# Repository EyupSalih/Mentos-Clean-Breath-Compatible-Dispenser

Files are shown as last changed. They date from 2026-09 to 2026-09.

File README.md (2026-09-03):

# Mentos Clean Breath Compatible V7 Dual‑Magazine Pocket Dispenser

> 3D-printable, spring-fed, dual-magazine pocket dispenser designed to fit **Mentos Clean Breath** tablets.  
> **30-tablet capacity (15 + 15)**, anti-jam cutoff shuttle, closed outer shell, removable magazines, single-button spring release, sliding bottom service cover and a hinged dust flap.

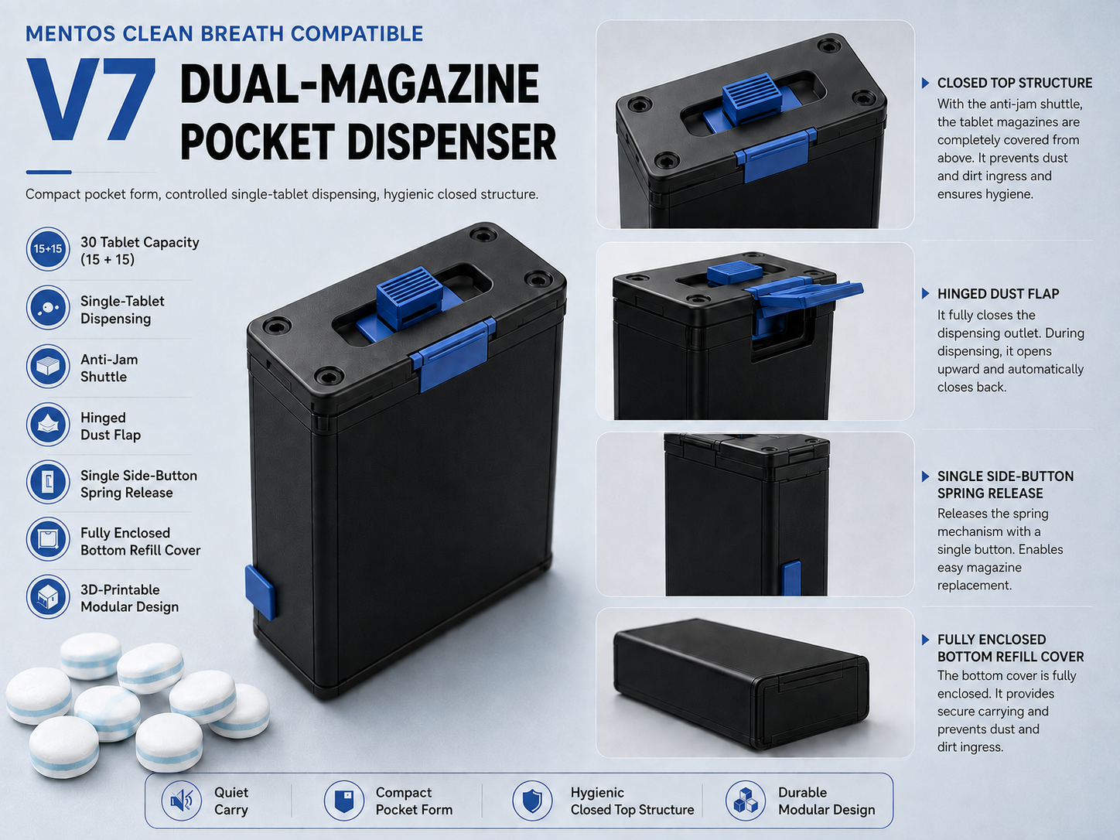
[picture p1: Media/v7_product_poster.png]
V7 product overview

Türkçe versiyon için "Media/v7_product_poster_TR.png"

## Project status

**V7 — functional CAD release**

The current digital CAD audit reports **no critical rigid-body collisions in the tested assembly and motion states**.  
This is **not** a physical certification. Before relying on the device for everyday use, validate the real print tolerances, spring force, TPU behavior, tablet batch variation and food-contact suitability of the materials you choose.

Nominal tablet model used in CAD:

- Diameter: **11.2 mm**
- Thickness: **5.9 mm**
- Maximum design envelope used in checks: **Ø11.55 × 6.20 mm**

## Key features

- **30-tablet capacity** — two removable 15-tablet magazines
- **Spring + follower feed system** in each magazine
- **Double-J follower lock** so the magazines can be filled while the springs remain restrained
- **Single side release button** releases both magazine followers after the case is closed
- **Closed exterior shell** — no long follower slots on the outside
- **Dual-pocket cutoff shuttle** — blocks the feed openings while moving to reduce double-feeds/jams
- **Raised thumb tab** for easier left/right operation
- **Hinged output dust flap**
- **Full-width sliding bottom service cover** — routine refill does not require removing the top screws
- **TPU/silicone anti-rattle elements**
- STEP source geometry, printable STL files, assembly-state CAD, hardware references and audit files included

## How it works

1. Remove a magazine from the body.
2. Remove the TPU feed ring.
3. Use the refill push-twist tool to push the follower down and rotate it into the **double-J lock**.
4. Load **15 tablets**.
5. Reinstall the TPU feed ring.
6. Repeat for the second magazine.
7. Insert both magazines into the chassis **while their springs are still locked**.
8. Close the sliding bottom cover.
9. Press the recessed side button once; the internal common release bar unlocks both followers.
10. Move the top shuttle left or right to bring one tablet to the center output.
11. Open the dust flap and remove the tablet.
12. Return the shuttle to the center/feed position.

## Assembly video

A detailed X-ray-style assembly, refill and usage video is included:

**[Watch / download the V7 assembly video](Media/V7_XRAY_assembly_fill_use_30fps.mp4)**

The video uses transparent/X-ray views where the outer shell would otherwise hide the internal mechanism.

## Repository structure

```text
.
├── README.md
├── README_TR.md
├── LICENSE.md
├── LICENSE-CAD.md
├── LICENSE-SOFTWARE
├── GITHUB_SETUP.md
├── ASSEMBLY_STATES/
│   ├── 01_COMPLETE_30_LOADED_RELEASED.step
│   ├── 02_CUTAWAY_INTERNALS.step
│   └── ...
├── STEP_parts/
│   ├── 01_lower_chassis_closed_shell.step
│   ├── 02_transfer_base_metering_deck.step
│   ├── 03_top_cap_real_screw_access.step
│   └── ...
├── STL_printable/
│   ├── 01_lower_chassis_closed_shell.stl
│   ├── 02_transfer_base_metering_deck.stl
│   ├── 03_top_cap_real_screw_access.stl
│   └── ...
├── REFERENCE_hardware/
├── AUDIT/
├── SOURCE/
└── media/
    ├── v7_product_poster.png
    └── V7_XRAY_assembly_fill_use_30fps.mp4
```

For the detailed Turkish mechanical description, see **[README_TR.md](README_TR.md)**.

## Main printable parts

| No. | Part | Suggested material | Qty |
|---:|---|---|---:|
| 01 | Lower chassis / closed shell | PETG / ASA | 1 |
| 02 | Transfer base / metering deck | PETG / ASA | 1 |
| 03 | Top cap | PETG / ASA | 1 |
| 04 | Left magazine | PETG / ASA | 1 |
| 05 | Right magazine | PETG / ASA | 1 |
| 06 | Double-stem follower | PETG / ASA | 2 |
| 07 | Feed ring | TPU | 2 |
| 08 | Dual-pocket cutoff shuttle | PETG / ASA | 1 |
| 09 | Common release bar | PETG / ASA | 1 |
| 10 | Side-button dust seal | TPU | 1 |
| 11 | Output dust flap | TPU | 1 |
| 12 | Sliding bottom outer cover | PETG / ASA | 1 |
| 13 | Bottom preload pad | TPU | 2 |
| 14 | Refill push-twist tool | PETG / ASA | 1 |

See `AUDIT/V7_BOM_TR.csv` for the full bill of materials and hardware references.

## Referenced hardware

The repository contains reference CAD for the hardware used by the design, including:

- 2 × main compression springs
- 1 × release-button return spring
- 4 × M2.5 countersunk screws
- 4 × M2.5 heat-set inserts
- M3 shuttle center detent ball plunger
- M3 bottom-cover detent ball plunger
- 1.5 mm food-grade silicone cord

**Reference CAD is dimensional guidance only.** Match the physical hardware you actually purchase and verify dimensions before printing the final parts.

## Printing and material notes

PETG or ASA is recommended for the main rigid parts. Flexible sealing/feed parts are designed around TPU-type behavior.

If this device will directly contact food/tablets:

- choose materials whose manufacturer documents suitability for your intended contact use,
- consider nozzle, printer and post-processing contamination,
- clean parts appropriately,
- do not assume that a material is food-safe solely because it is sold as PETG or TPU.

## CAD audit and limitations

Audit material is stored in `AUDIT/`.

The digital checks cover selected rigid-body collisions, assembly paths and motion states. They **cannot** fully predict:

- FDM dimensional error
- layer orientation strength
- wear after repeated cycling
- actual spring-force curve
- TPU Shore hardness differences
- tablet manufacturing variation
- long-term dust sealing
- real-world impact/drop behavior

Physical prototype testing remains necessary.

## Licensing

This repository uses **split licensing**:

- CAD, STEP/STL files, documentation, images and project media: **CC BY-NC-SA 4.0**
- Source code / utility scripts in `SOURCE/`: **MIT License**

See [LICENSE.md](LICENSE.md), [LICENSE-CAD.md](LICENSE-CAD.md) and [LICENSE-SOFTWARE](LICENSE-SOFTWARE).

The non-commercial restriction means the design files may not be used commercially under the CC license without separate permission from the rights holder.

## Trademark / affiliation disclaimer

**Mentos** and **Mentos Clean Breath** are trademarks of their respective owners.  
This is an **independent, unofficial compatibility project** and is not affiliated with, sponsored by, approved by or endorsed by Mentos or Perfetti Van Melle.

The product name is used only to identify the tablet format the design is intended to fit.

## Contributions and modifications

Issues, tolerance measurements, print results and mechanical improvements are welcome.

If you publish a modified version of the licensed CAD/design material, follow the attribution and ShareAlike requirements in `LICENSE-CAD.md`.

---

### Türkçe kısa özet

Bu repo, Mentos Clean Breath tabletleri için tasarlanmış **15 + 15 kapasiteli çift şarjörlü, yay beslemeli V7 cep dispenserinin** STEP/STL dosyalarını, montaj durumlarını, audit dosyalarını ve detaylı X-ray montaj videosunu içerir. Ayrıntılı Türkçe teknik açıklama için **[README_TR.md](README_TR.md)** dosyasına bakın.

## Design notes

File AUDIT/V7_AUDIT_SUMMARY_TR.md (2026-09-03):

# V7 CAD Audit Özeti — Magazine Retention V2

Şarjör tutucu kasa revizyonunda önceki alt C-kılavuzların, şarjör alttan takılırken kilitli/18° döndürülmüş follower saplarının montaj yoluna girdiği tespit edildi. Final oturma konumu çarpışmasızdı; sorun yalnızca montaj yolunda yaklaşık -8 mm ara konumda oluşuyordu.

Yeni kasada follower saplarının ön/arka süpürme bölgesi tamamen açık bırakıldı. Şarjörleri Y yönünde tutmak için mevcut yan raylara bağlı, follower saplarından uzakta kalan dört diyagonal sarma kılavuzu kullanıldı. Nominal şarjör ile kılavuz arasında yaklaşık 0,35 mm radyal çalışma boşluğu korunur.

Kontrol edilen kritik zincirler: tek bağlı basılabilir katılar, follower stroku, çift taraflı J kilidi, yay kilitliyken şarjörün alttan tüm montaj yolu, tek yan butonlu ortak release bar, sürgülü alt kapak, cutoff shuttle, ikinci tablet anti-jam düzlemi, worst-case tablet çıkışı, feed keepout ve vida/tornavida erişimi.

Son gate: **CAD_GATE_PASS / 0 kritik hata**.

Not: CAD audit fiziksel baskı doğrulamasının yerine geçmez; FDM toleransı, gerçek yay kuvveti, TPU sertliği ve gerçek şeker parti toleransları baskıda kontrol edilmelidir.

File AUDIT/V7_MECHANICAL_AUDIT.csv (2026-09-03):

test | value | expected | severity | note
connected_solids::chassis | 1 | 1 | CRITICAL
valid_shape::chassis | 1 | 1 | CRITICAL
connected_solids::transfer_base | 1 | 1 | CRITICAL
valid_shape::transfer_base | 1 | 1 | CRITICAL
connected_solids::top_cap | 1 | 1 | CRITICAL
valid_shape::top_cap | 1 | 1 | CRITICAL
connected_solids::magazine | 1 | 1 | CRITICAL
valid_shape::magazine | 1 | 1 | CRITICAL
connected_solids::follower | 1 | 1 | CRITICAL
valid_shape::follower | 1 | 1 | CRITICAL
connected_solids::shuttle | 1 | 1 | CRITICAL
valid_shape::shuttle | 1 | 1 | CRITICAL
connected_solids::release_bar | 1 | 1 | CRITICAL
valid_shape::release_bar | 1 | 1 | CRITICAL
connected_solids::bottom_cover | 1 | 1 | CRITICAL
valid_shape::bottom_cover | 1 | 1 | CRITICAL
magL_vs_chassis | 0.0 | 0 | CRITICAL
magR_vs_chassis | 0.0 | 0 | CRITICAL
base_vs_chassis | 0.0 | 0 | CRITICAL
topcap_vs_base | 0.0 | 0 | CRITICAL
bottomcover_vs_chassis_closed | 0.0 | 0 | CRITICAL
releasebar_rest_vs_chassis | 0.0 | 0 | CRITICAL
releasebar_rest_vs_magL | 0.0 | 0 | CRITICAL
releasebar_rest_vs_magR | 0.0 | 0 | CRITICAL
L_follower_vs_mag_z12.4 | 0.0 | 0 | CRITICAL
L_follower_vs_closed_shell_z12.4 | 0.0 | 0 | CRITICAL
L_follower_vs_mag_z20 | 0.0 | 0 | CRITICAL
L_follower_vs_closed_shell_z20 | 0.0 | 0 | CRITICAL
L_follower_vs_mag_z40 | 0.0 | 0 | CRITICAL
L_follower_vs_closed_shell_z40 | 0.0 | 0 | CRITICAL
L_follower_vs_mag_z65 | 0.0 | 0 | CRITICAL
L_follower_vs_closed_shell_z65 | 0.0 | 0 | CRITICAL
L_follower_vs_mag_z90 | 0.0 | 0 | CRITICAL
L_follower_vs_closed_shell_z90 | 0.0 | 0 | CRITICAL
L_follower_vs_mag_z103.7 | 0.0 | 0 | CRITICAL
L_follower_vs_closed_shell_z103.7 | 0.0 | 0 | CRITICAL
R_follower_vs_mag_z12.4 | 0.0 | 0 | CRITICAL
R_follower_vs_closed_shell_z12.4 | 0.0 | 0 | CRITICAL
R_follower_vs_mag_z20 | 0.0 | 0 | CRITICAL
R_follower_vs_closed_shell_z20 | 0.0 | 0 | CRITICAL
R_follower_vs_mag_z40 | 0.0 | 0 | CRITICAL
R_follower_vs_closed_shell_z40 | 0.0 | 0 | CRITICAL
R_follower_vs_mag_z65 | 0.0 | 0 | CRITICAL
R_follower_vs_closed_shell_z65 | 0.0 | 0 | CRITICAL
R_follower_vs_mag_z90 | 0.0 | 0 | CRITICAL
R_follower_vs_closed_shell_z90 | 0.0 | 0 | CRITICAL
R_follower_vs_mag_z103.7 | 0.0 | 0 | CRITICAL
R_follower_vs_closed_shell_z103.7 | 0.0 | 0 | CRITICAL
doubleJ_rotation_0 | 0.0 | 0 | CRITICAL | Both stems rotate within symmetric J windows.
doubleJ_rotation_6 | 0.0 | 0 | CRITICAL | Both stems rotate within symmetric J windows.
doubleJ_rotation_12 | 0.0 | 0 | CRITICAL | Both stems rotate within symmetric J windows.
doubleJ_rotation_18 | 0.000324 | 0 | CRITICAL | Both stems rotate within symmetric J windows.
L_locked_mag_insert_-60 | 0.0 | 0 | CRITICAL | Spring remains locked while inserting magazine.
L_locked_mag_insert_-35 | 0.0 | 0 | CRITICAL | Spring remains locked while inserting magazine.
L_locked_mag_insert_-18 | 0.0 | 0 | CRITICAL | Spring remains locked while inserting magazine.
L_locked_mag_insert_-8 | 0.0 | 0 | CRITICAL | Spring remains locked while inserting magazine.
L_locked_mag_insert_0 | 0.0 | 0 | CRITICAL | Spring remains locked while inserting magazine.
R_locked_mag_insert_-60 | 0.0 | 0 | CRITICAL | Spring remains locked while inserting magazine.
R_locked_mag_insert_-35 | 0.0 | 0 | CRITICAL | Spring remains locked while inserting magazine.
R_locked_mag_insert_-18 | 0.0 | 0 | CRITICAL | Spring remains locked while inserting magazine.
R_locked_mag_insert_-8 | 0.0 | 0 | CRITICAL | Spring remains locked while inserting magazine.
R_locked_mag_insert_0 | 0.0 | 0 | CRITICAL | Spring remains locked while inserting magazine.
release_sweep_0 | 0.0 | 0 | CRITICAL | Internal bar clears rigid housing.
release_sweep_0.5 | 0.0 | 0 | CRITICAL | Internal bar clears rigid housing.
release_sweep_1.0 | 0.0 | 0 | CRITICAL | Internal bar clears rigid housing.
release_sweep_1.5 | 0.0 | 0 | CRITICAL | Internal bar clears rigid housing.
release_sweep_2.0 | 0.0 | 0 | CRITICAL | Internal bar clears rigid housing.
release_sweep_2.45 | 0.0 | 0 | CRITICAL | Internal bar clears rigid housing.
L_release_contact_rest | 0.0 | 0 | CRITICAL
L_release_contact_press | 4.250313 | >0 intentional | CRITICAL | Pusher nose reaches locked rear stem.
R_release_contact_rest | 0.0 | 0 | CRITICAL
R_release_contact_press | 4.250313 | >0 intentional | CRITICAL | Pusher nose reaches locked rear stem.
bottom_cover_slide_y34 | 0.0 | 0 | CRITICAL | Full outer cover slides without screw removal.
bottom_cover_slide_y28 | 0.0 | 0 | CRITICAL | Full outer cover slides without screw removal.
bottom_cover_slide_y22 | 0.0 | 0 | CRITICAL | Full outer cover slides without screw removal.
bottom_cover_slide_y16 | 0.0 | 0 | CRITICAL | Full outer cover slides without screw removal.
bottom_cover_slide_y10 | 0.0 | 0 | CRITICAL | Full outer cover slides without screw removal.
bottom_cover_slide_y5 | 0.0 | 0 | CRITICAL | Full outer cover slides without screw removal.
bottom_cover_slide_y0 | 0.0 | 0 | CRITICAL | Full outer cover slides without screw removal.
shuttle_rigid_-9.5 | 0.0 | 0 | CRITICAL
L_carried_nom_-9.5 | 0.0 | 0 | CRITICAL
L_carried_MAX_-9.5 | 0.0 | 0 | CRITICAL
R_carried_nom_-9.5 | 0.0 | 0 | CRITICAL
R_carried_MAX_-9.5 | 0.0 | 0 | CRITICAL
L_next_vs_cutoff_-9.5 | 0.0 | 0 | CRITICAL | Second candy stays below moving cutoff plane.
R_next_vs_cutoff_-9.5 | 0.0 | 0 | CRITICAL | Second candy stays below moving cutoff plane.
shuttle_rigid_-6.33 | 0.0 | 0 | CRITICAL
L_carried_nom_-6.33 | 0.0 | 0 | CRITICAL
L_carried_MAX_-6.33 | 0.0 | 0 | CRITICAL
R_carried_nom_-6.33 | 0.0 | 0 | CRITICAL
R_carried_MAX_-6.33 | 0.0 | 0 | CRITICAL
L_next_vs_cutoff_-6.33 | 0.0 | 0 | CRITICAL | Second candy stays below moving cutoff plane.
R_next_vs_cutoff_-6.33 | 0.0 | 0 | CRITICAL | Second candy stays below moving cutoff plane.
shuttle_rigid_-3.17 | 0.0 | 0 | CRITICAL
L_carried_nom_-3.17 | 0.0 | 0 | CRITICAL
L_carried_MAX_-3.17 | 0.0 | 0 | CRITICAL
R_carried_nom_-3.17 | 0.0 | 0 | CRITICAL
R_carried_MAX_-3.17 | 0.0 | 0 | CRITICAL
L_next_vs_cutoff_-3.17 | 0.0 | 0 | CRITICAL | Second candy stays below moving cutoff plane.
R_next_vs_cutoff_-3.17 | 0.0 | 0 | CRITICAL | Second candy stays below moving cutoff plane.
shuttle_rigid_0 | 0.0 | 0 | CRITICAL
L_carried_nom_0 | 0.0 | 0 | CRITICAL
L_carried_MAX_0 | 0.0 | 0 | CRITICAL
R_carried_nom_0 | 0.0 | 0 | CRITICAL
R_carried_MAX_0 | 0.0 | 0 | CRITICAL
L_next_vs_cutoff_0 | 0.0 | 0 | CRITICAL | Second candy stays below moving cutoff plane.
R_next_vs_cutoff_0 | 0.0 | 0 | CRITICAL | Second candy stays below moving cutoff plane.
shuttle_rigid_3.17 | 0.0 | 0 | CRITICAL
L_carried_nom_3.17 | 0.0 | 0 | CRITICAL
L_carried_MAX_3.17 | 0.0 | 0 | CRITICAL
R_carried_nom_3.17 | 0.0 | 0 | CRITICAL
R_carried_MAX_3.17 | 0.0 | 0 | CRITICAL
L_next_vs_cutoff_3.17 | 0.0 | 0 | CRITICAL | Second candy stays below moving cutoff plane.
R_next_vs_cutoff_3.17 | 0.0 | 0 | CRITICAL | Second candy stays below moving cutoff plane.
shuttle_rigid_6.33 | 0.0 | 0 | CRITICAL
L_carried_nom_6.33 | 0.0 | 0 | CRITICAL
L_carried_MAX_6.33 | 0.0 | 0 | CRITICAL
R_carried_nom_6.33 | 0.0 | 0 | CRITICAL
R_carried_MAX_6.33 | 0.0 | 0 | CRITICAL
L_next_vs_cutoff_6.33 | 0.0 | 0 | CRITICAL | Second candy stays below moving cutoff plane.
R_next_vs_cutoff_6.33 | 0.0 | 0 | CRITICAL | Second candy stays below moving cutoff plane.
shuttle_rigid_9.5 | 0.0 | 0 | CRITICAL
L_carried_nom_9.5 | 0.0 | 0 | CRITICAL
L_carried_MAX_9.5 | 0.0 | 0 | CRITICAL
R_carried_nom_9.5 | 0.0 | 0 | CRITICAL
R_carried_MAX_9.5 | 0.0 | 0 | CRITICAL
L_next_vs_cutoff_9.5 | 0.0 | 0 | CRITICAL | Second candy stays below moving cutoff plane.
R_next_vs_cutoff_9.5 | 0.0 | 0 | CRITICAL | Second candy stays below moving cutoff plane.
LEFT_DISPENSE_L_SOURCE_BLOCK | 373.656037 | >0 blocked | CRITICAL | Solid cutoff covers source when shuttle leaves neutral.
LEFT_DISPENSE_R_SOURCE_BLOCK | 252.120911 | >0 blocked | CRITICAL | Solid cutoff covers source when shuttle leaves neutral.
RIGHT_DISPENSE_L_SOURCE_BLOCK | 252.12091 | >0 blocked | CRITICAL | Solid cutoff covers source when shuttle leaves neutral.
RIGHT_DISPENSE_R_SOURCE_BLOCK | 373.656037 | >0 blocked | CRITICAL | Solid cutoff covers source when shuttle leaves neutral.
L_neutral_MAX_feed | 0.0 | 0 | CRITICAL
R_neutral_MAX_feed | 0.0 | 0 | CRITICAL
exit_R_POCKET_0 | 0.0 | 0 | CRITICAL
exit_MAX_R_POCKET_0 | 0.0 | 0 | CRITICAL
exit_R_POCKET_-2 | 0.0 | 0 | CRITICAL
exit_MAX_R_POCKET_-2 | 0.0 | 0 | CRITICAL
exit_R_POCKET_-4 | 0.0 | 0 | CRITICAL
exit_MAX_R_POCKET_-4 | 0.0 | 0 | CRITICAL
exit_R_POCKET_-6 | 0.0 | 0 | CRITICAL
exit_MAX_R_POCKET_-6 | 0.0 | 0 | CRITICAL
exit_R_POCKET_-8 | 0.0 | 0 | CRITICAL
exit_MAX_R_POCKET_-8 | 0.0 | 0 | CRITICAL
exit_R_POCKET_-10 | 0.0 | 0 | CRITICAL
exit_MAX_R_POCKET_-10 | 0.0 | 0 | CRITICAL
exit_R_POCKET_-12 | 0.0 | 0 | CRITICAL
exit_MAX_R_POCKET_-12 | 0.0 | 0 | CRITICAL
exit_R_POCKET_-14 | 0.0 | 0 | CRITICAL
exit_MAX_R_POCKET_-14 | 0.0 | 0 | CRITICAL
exit_L_POCKET_0 | 0.0 | 0 | CRITICAL
exit_MAX_L_POCKET_0 | 0.0 | 0 | CRITICAL
exit_L_POCKET_-2 | 0.0 | 0 | CRITICAL
exit_MAX_L_POCKET_-2 | 0.0 | 0 | CRITICAL
exit_L_POCKET_-4 | 0.0 | 0 | CRITICAL
exit_MAX_L_POCKET_-4 | 0.0 | 0 | CRITICAL
exit_L_POCKET_-6 | 0.0 | 0 | CRITICAL
exit_MAX_L_POCKET_-6 | 0.0 | 0 | CRITICAL
exit_L_POCKET_-8 | 0.0 | 0 | CRITICAL
exit_MAX_L_POCKET_-8 | 0.0 | 0 | CRITICAL
exit_L_POCKET_-10 | 0.0 | 0 | CRITICAL
exit_MAX_L_POCKET_-10 | 0.0 | 0 | CRITICAL
exit_L_POCKET_-12 | 0.0 | 0 | CRITICAL
exit_MAX_L_POCKET_-12 | 0.0 | 0 | CRITICAL
exit_L_POCKET_-14 | 0.0 | 0 | CRITICAL
exit_MAX_L_POCKET_-14 | 0.0 | 0 | CRITICAL
L_cap_feed_keepout | 0.0 | 0 | CRITICAL
R_cap_feed_keepout | 0.0 | 0 | CRITICAL
screwdriver_0_vs_shuttle_L | 0.0 | 0 | CRITICAL
screwdriver_0_vs_shuttle_C | 0.0 | 0 | CRITICAL
screwdriver_0_vs_shuttle_R | 0.0 | 0 | CRITICAL
screwdriver_1_vs_shuttle_L | 0.0 | 0 | CRITICAL
screwdriver_1_vs_shuttle_C | 0.0 | 0 | CRITICAL
screwdriver_1_vs_shuttle_R | 0.0 | 0 | CRITICAL
screwdriver_2_vs_shuttle_L | 0.0 | 0 | CRITICAL
screwdriver_2_vs_shuttle_C | 0.0 | 0 | CRITICAL
screwdriver_2_vs_shuttle_R | 0.0 | 0 | CRITICAL
screwdriver_3_vs_shuttle_L | 0.0 | 0 | CRITICAL
screwdriver_3_vs_shuttle_C | 0.0 | 0 | CRITICAL
screwdriver_3_vs_shuttle_R | 0.0 | 0 | CRITICAL
thumb_tab_height_above_cap_mm | 3.3 | >=2.8 | HIGH
bottom_cover_width_mm | 59.0 | >=59 | HIGH
bottom_cover_depth_mm | 30.7 | >=28 | HIGH

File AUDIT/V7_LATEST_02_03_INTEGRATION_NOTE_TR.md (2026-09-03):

# V7 Son 02/03 Entegrasyon Notu

Bu paket son kullanıcı revizyonlarından sonra yeniden oluşturulmuştur.

## Güncellenen parçalar
- 02_transfer_base_metering_deck: çevresel boşluk kapatma korunmuş, 08 shuttle'ın tam sağ-sol hareket zarfındaki yan çakışma kaldırılmıştır.
- 03_top_cap_real_screw_access: iç sandviç hava boşluğu doldurulmuş, orijinal pim menteşe geometrisi birebir korunmuş, 11 kapağın 0-90° açılma yolu serbest bırakılmıştır.

Her iki parçanın STEP ve STL karşılıkları güncellenmiştir. ASSEMBLY_STATES klasöründeki 9 birleşik STEP dosyası da bu güncel 02/03 geometrileri kullanılarak yeniden oluşturulmuştur.

## Değişen arayüzlerin hedefli kontrolü
- 01 ↔ 02: 0 mm³ çakışma
- 02 ↔ 03: 0 mm³ çakışma
- 02 ↔ 08 shuttle, tam strok: 0 mm³
- 03 ↔ 08 shuttle, tam strok: 0 mm³
- 02 ↔ 11 kapalı: 0 mm³
- 03 ↔ 11 kapak, 0–90°: 0 mm³
- Dört M2.5 vida koridoru: açık / PASS
- 02 ve 03: tek bağlı, geçerli solid

Not: Bu dosya sonradan değişen 02/03 arayüzlerinin yeniden doğrulamasıdır; fiziksel baskı toleransı, yay kuvveti ve TPU davranışı gerçek prototipte ayrıca doğrulanmalıdır.

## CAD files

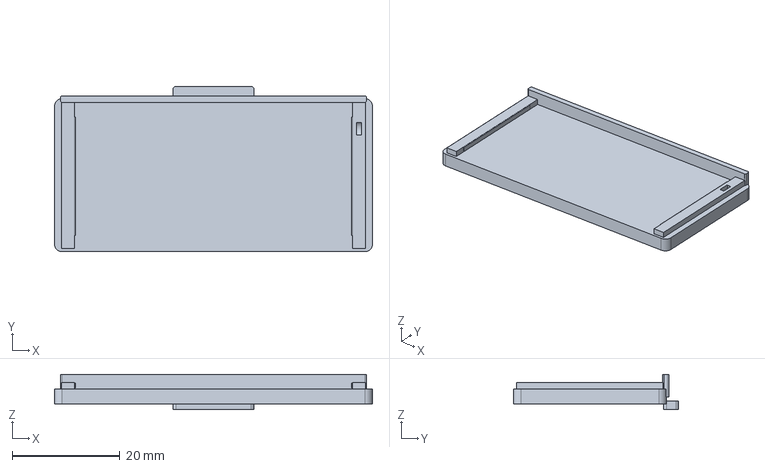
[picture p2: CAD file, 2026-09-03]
STEP_parts/12_full_sliding_bottom_outer_cover.step
59.0 x 30.7 x 6.55 mm

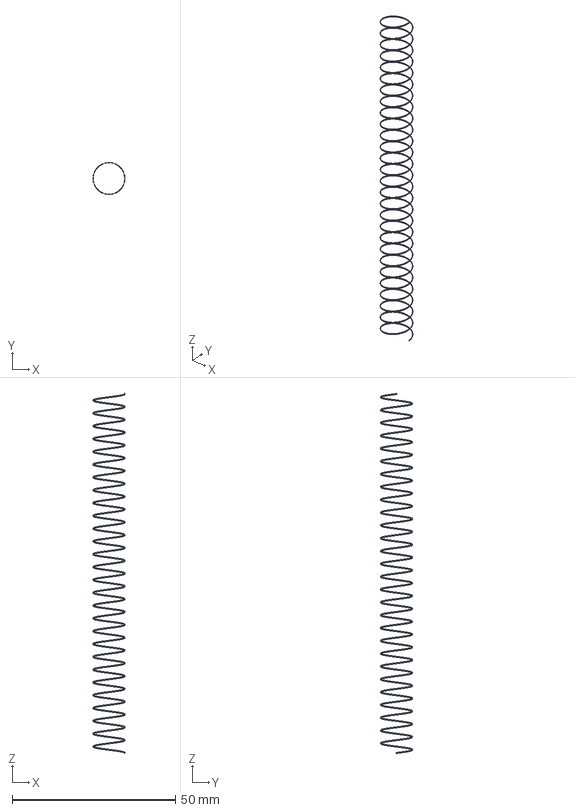
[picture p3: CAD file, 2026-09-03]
REFERENCE_hardware/main_spring_10p05OD_0p32wire_110free_reference.step
9.73 x 9.73 x 110.3 mm

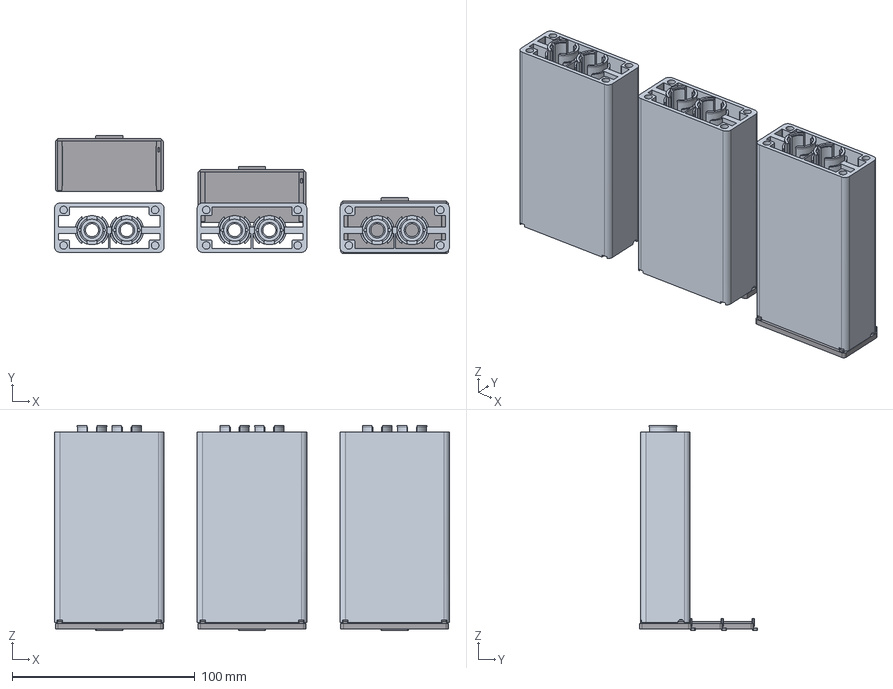
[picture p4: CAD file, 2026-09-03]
ASSEMBLY_STATES/06_FULL_SLIDING_BOTTOM_COVER_SERVICE.step
216.0 x 64.7 x 112.3 mm
chassis_OPEN_REAR
cover_OPEN_REAR
magL_OPEN_REAR
magR_OPEN_REAR
chassis_HALF_SLIDE
cover_HALF_SLIDE
magL_HALF_SLIDE
magR_HALF_SLIDE
chassis_CLOSED
cover_CLOSED
magL_CLOSED
magR_CLOSED

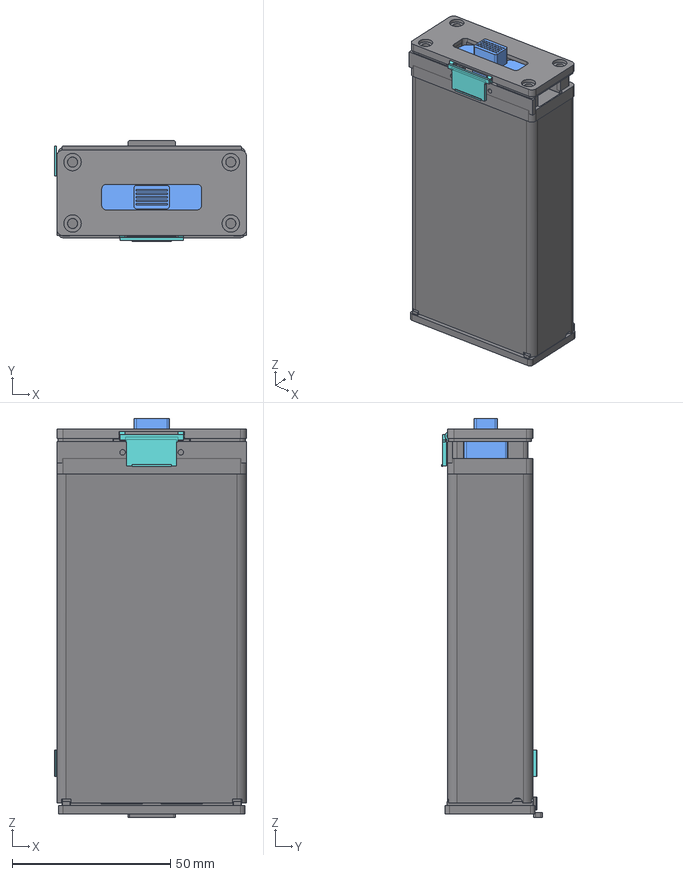
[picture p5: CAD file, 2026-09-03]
ASSEMBLY_STATES/01_COMPLETE_30_LOADED_RELEASED.step
60.8 x 31.9 x 126.1 mm
closed_outer_chassis
metering_deck
top_cap
sliding_bottom_cover
cutoff_shuttle
internal_release_bar
TPU_output_flap
TPU_side_button_seal
mag_L
follower_L
feed_ring_L
bottom_pad_L
spring_L
tablet_L_01
tablet_L_02
tablet_L_03
tablet_L_04
tablet_L_05
tablet_L_06
tablet_L_07
tablet_L_08
tablet_L_09
tablet_L_10
tablet_L_11
tablet_L_12
tablet_L_13
tablet_L_14
tablet_L_15
mag_R
follower_R
feed_ring_R
bottom_pad_R
spring_R
tablet_R_01
tablet_R_02
tablet_R_03
tablet_R_04
tablet_R_05
tablet_R_06
tablet_R_07
tablet_R_08
tablet_R_09
tablet_R_10
tablet_R_11
tablet_R_12
tablet_R_13
tablet_R_14
tablet_R_15

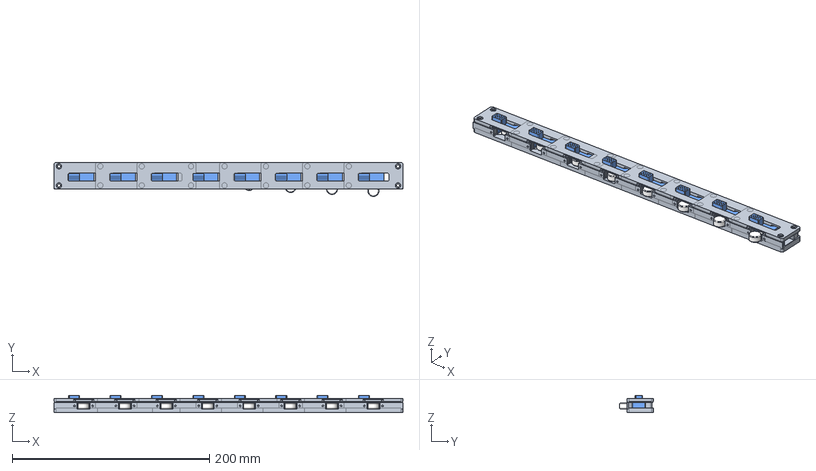
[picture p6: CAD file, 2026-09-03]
ASSEMBLY_STATES/08_OUTPUT_EXTRACTION_SEQUENCE.step
354.0 x 34.4 x 17.5 mm
deck_0
shuttle_0
cap_0
tablet_0
deck_1
shuttle_1
cap_1
tablet_1
deck_2
shuttle_2
cap_2
tablet_2
deck_3
shuttle_3
cap_3
tablet_3
deck_4
shuttle_4
cap_4
tablet_4
deck_5
shuttle_5
cap_5
tablet_5
deck_6
shuttle_6
cap_6
tablet_6
deck_7
shuttle_7
cap_7
tablet_7

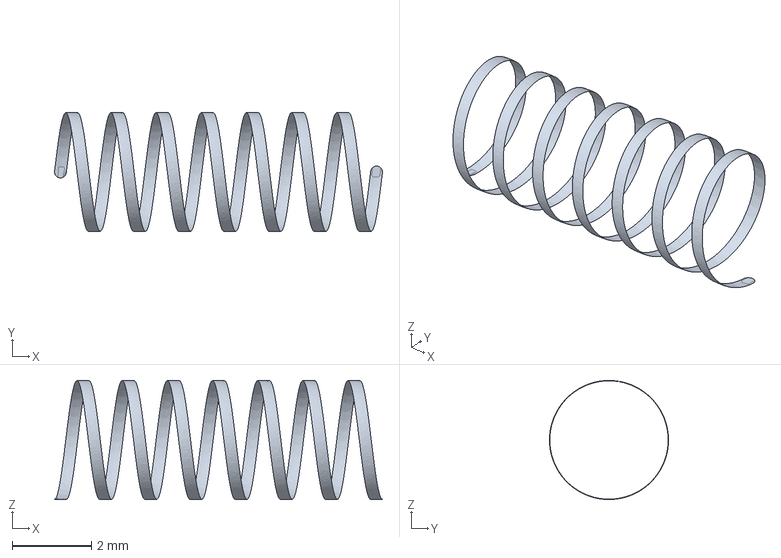
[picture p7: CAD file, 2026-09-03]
REFERENCE_hardware/release_button_return_spring_reference.step
8.30 x 3.01 x 3.01 mm

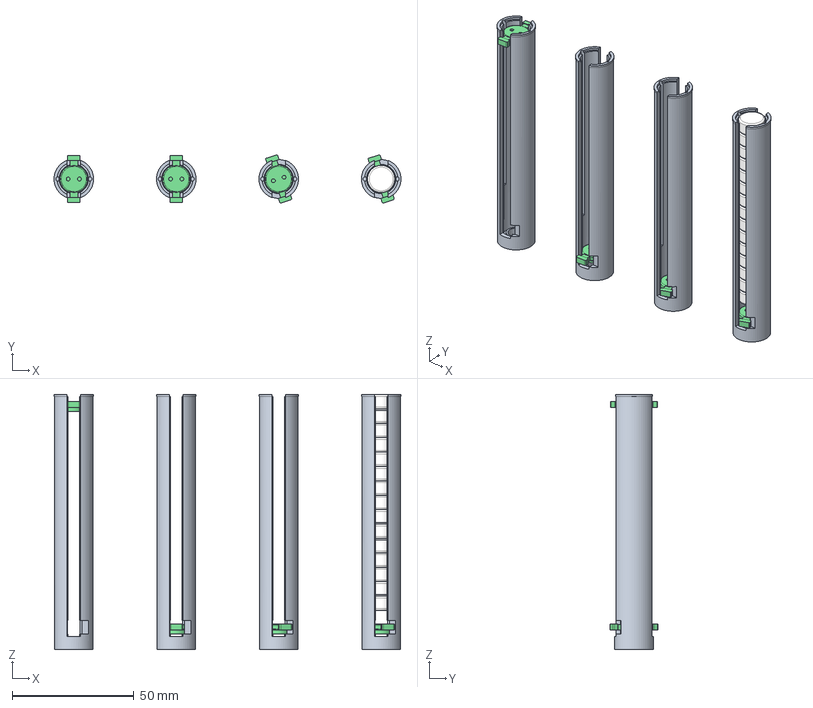
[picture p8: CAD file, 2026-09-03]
ASSEMBLY_STATES/03_MAGAZINE_DOUBLE_J_REFILL_SEQUENCE.step
142.2 x 19.8 x 104.6 mm
mag_EMPTY_UP
follower_EMPTY_UP
mag_PUSH_DOWN
follower_PUSH_DOWN
mag_TWIST_LOCK
follower_TWIST_LOCK
mag_READY_FILLED
follower_READY_FILLED
candy_0
candy_1
candy_2
candy_3
candy_4
candy_5
candy_6
candy_7
candy_8
candy_9
candy_10
candy_11
candy_12
candy_13
candy_14

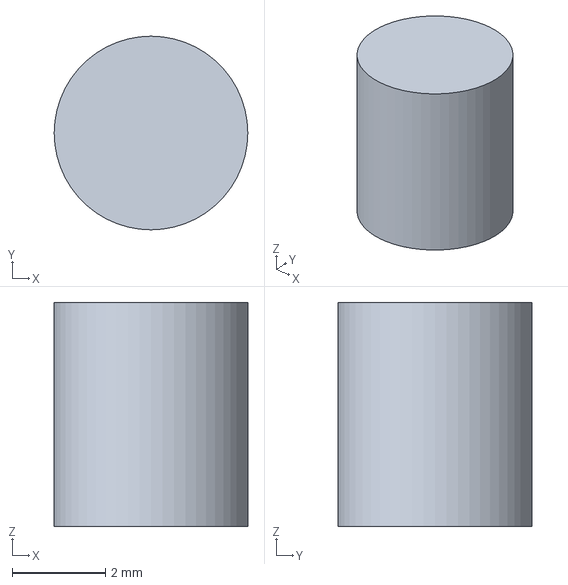
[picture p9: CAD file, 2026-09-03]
REFERENCE_hardware/M2p5_heatset_insert_reference.step
4.15 x 4.15 x 4.80 mm

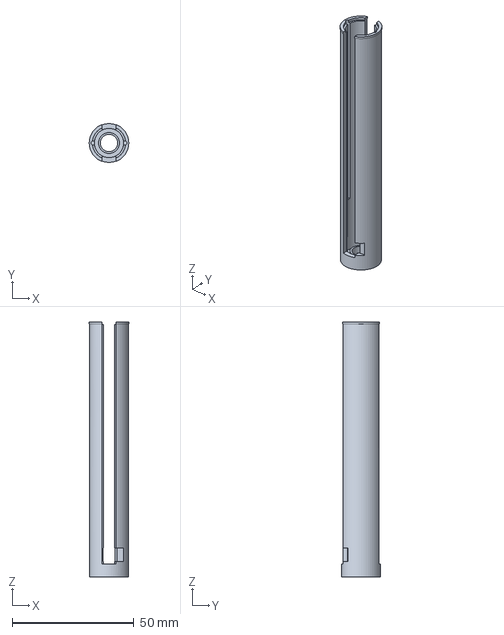
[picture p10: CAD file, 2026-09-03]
STEP_parts/05_magazine_RIGHT_double_J.step
16.2 x 15.9 x 104.6 mm

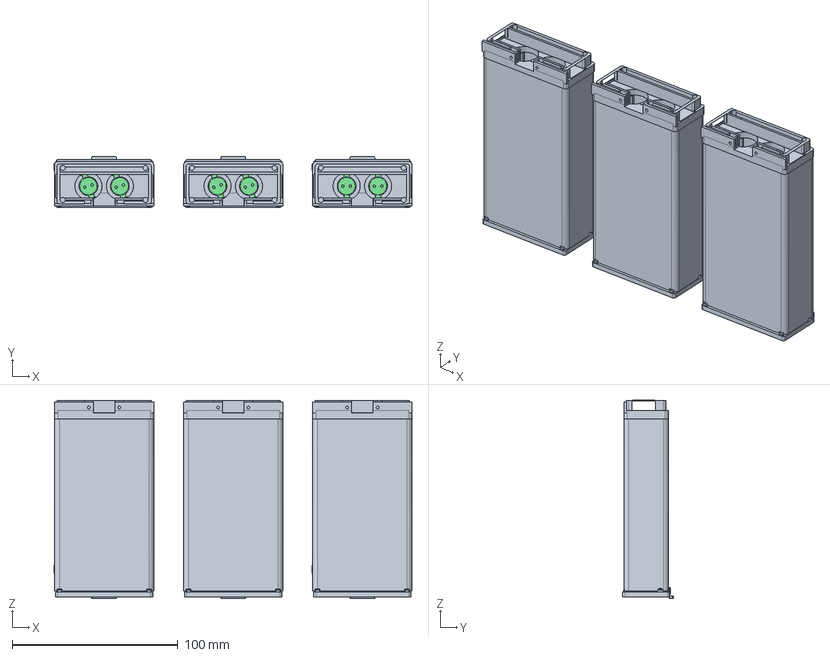
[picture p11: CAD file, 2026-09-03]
ASSEMBLY_STATES/04_CLOSE_CASE_THEN_SIDE_BUTTON_DUAL_RELEASE.step
216.3 x 30.7 x 119.6 mm
chassis_CASE_CLOSED_LOCKED
deck_CASE_CLOSED_LOCKED
cover_CASE_CLOSED_LOCKED
release_CASE_CLOSED_LOCKED
follower_L_CASE_CLOSED_LOCKED
follower_R_CASE_CLOSED_LOCKED
chassis_SIDE_BUTTON_PRESS
deck_SIDE_BUTTON_PRESS
cover_SIDE_BUTTON_PRESS
release_SIDE_BUTTON_PRESS
follower_L_SIDE_BUTTON_PRESS
follower_R_SIDE_BUTTON_PRESS
chassis_FOLLOWERS_RELEASED
deck_FOLLOWERS_RELEASED
cover_FOLLOWERS_RELEASED
release_FOLLOWERS_RELEASED
follower_L_FOLLOWERS_RELEASED
follower_R_FOLLOWERS_RELEASED

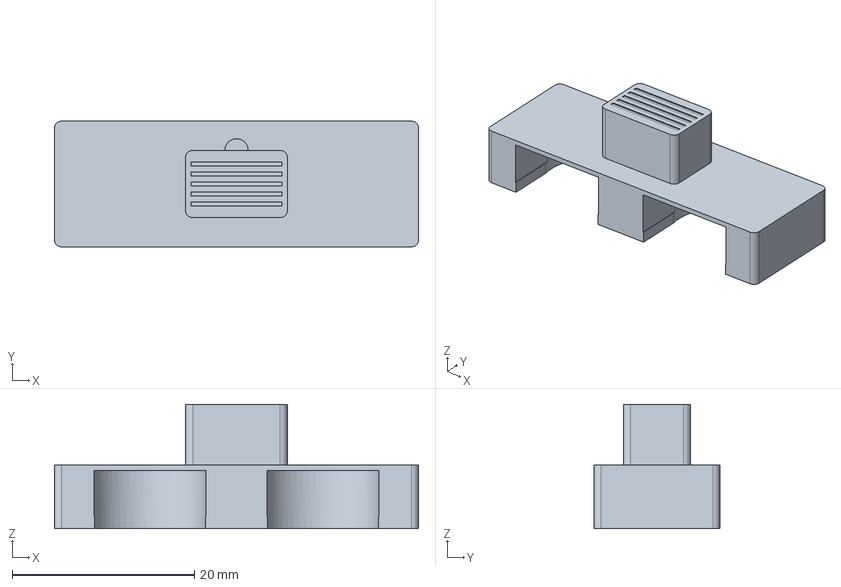
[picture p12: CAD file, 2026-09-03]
STEP_parts/08_dual_pocket_CUTOFF_shuttle.step
40.0 x 13.8 x 13.7 mm

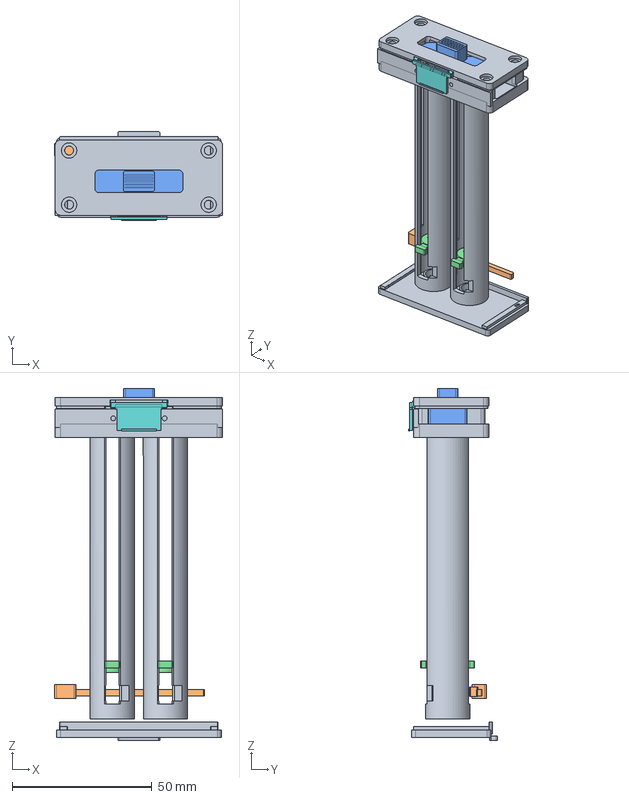
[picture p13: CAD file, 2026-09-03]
ASSEMBLY_STATES/02_CUTAWAY_INTERNALS.step
60.3 x 31.9 x 126.1 mm
deck
top_cap
magL
magR
shuttle
release_bar
bottom_cover
flap
follower_L
ring_L
follower_R
ring_R

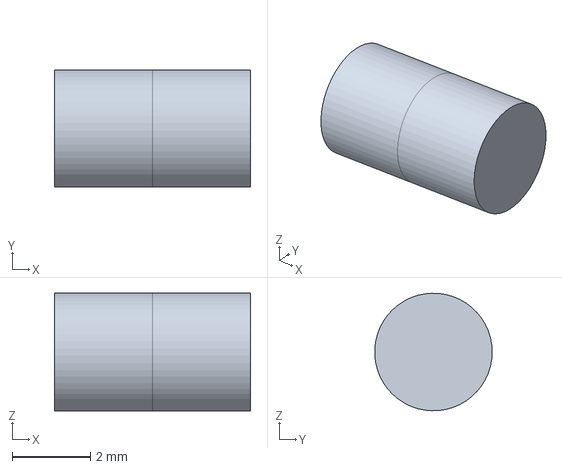
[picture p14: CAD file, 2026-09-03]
REFERENCE_hardware/M3_bottom_cap_ball_plunger_reference.step
5.00 x 3.00 x 3.00 mm

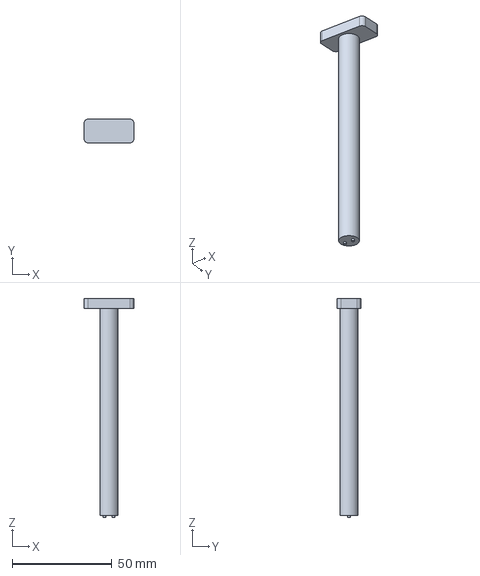
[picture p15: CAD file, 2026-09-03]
STEP_parts/14_refill_push_twist_tool.step
25.0 x 12.0 x 110.0 mm

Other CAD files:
REFERENCE_hardware/tablet_nominal_11p2x5p9.step
STEP_parts/02_transfer_base_metering_deck.step
ASSEMBLY_STATES/09_EXPLODED_ALL_PARTS.step
REFERENCE_hardware/M3_shuttle_center_detent_ball_plunger_reference.step
ASSEMBLY_STATES/05_SHUTTLE_CUTOFF_ANTI_JAM_STATES.step
ASSEMBLY_STATES/07_TOP_REAL_SCREW_INSTALLATION.step
REFERENCE_hardware/M2p5x12_countersunk_screw_reference.step
REFERENCE_hardware/food_grade_silicone_cord_1p5mm_reference.step
STEP_parts/01_lower_chassis_closed_shell.step
STEP_parts/03_top_cap_real_screw_access.step
STEP_parts/04_magazine_LEFT_double_J.step
STEP_parts/06_follower_double_stem_PRINT_2.step
STEP_parts/07_TPU_feed_ring_PRINT_2.step
STEP_parts/09_internal_common_release_bar.step
STEP_parts/10_TPU_side_button_seal.step
STEP_parts/11_TPU_output_dust_flap.step
STEP_parts/13_TPU_bottom_pad_PRINT_2.step
STL_printable/01_lower_chassis_closed_shell.stl
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
